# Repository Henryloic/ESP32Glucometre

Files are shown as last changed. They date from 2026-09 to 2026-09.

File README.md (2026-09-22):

# Guide utilisateur — Libre Sport Display ESP32-C3

**Libre Sport Display** is a small DIY device built with an ESP32-C3 and a 1.3-inch OLED screen. It displays the latest LibreLinkUp value and trend without opening the phone application.

## 1. Présentation

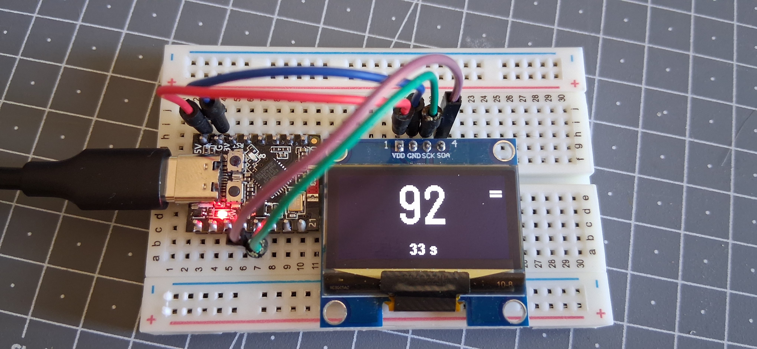
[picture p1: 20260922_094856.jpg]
Premier prototype


**Libre Sport Display** est un petit afficheur déporté basé sur un **ESP32-C3** et un écran OLED I²C de 1,3 pouce.

Il récupère périodiquement la dernière mesure disponible depuis le service LibreLinkUp et affiche uniquement les informations utiles pendant une activité sportive :

- la mesure instantanée en grand ;
- la tendance ;
- l’âge de la mesure ;
- l’état de la connexion en cas de problème.

L’objectif est de pouvoir consulter rapidement la valeur pendant une séance de tapis de course ou de vélo sur Zwift, sans avoir à ouvrir l’application sur le téléphone.

> [!IMPORTANT]
> Ce projet est un afficheur secondaire de confort. Il ne remplace ni l’application officielle, ni ses alarmes, ni les recommandations d’un professionnel de santé.

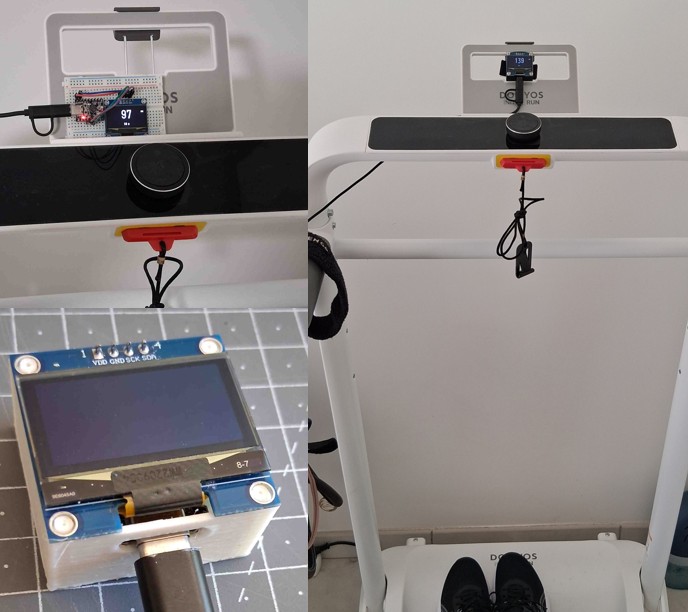
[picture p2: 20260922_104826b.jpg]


Boitier compact STL

---

## 2. Affichage

L’interface est volontairement très simple :

```text
┌─────────────────────┐
│              +      │
│        112          │
│        35 s         │
└─────────────────────┘
```

### Signification des tendances

| Code reçu | Affichage | Signification |
|---:|:---:|---|
| 1 | `--` | baisse rapide |
| 2 | `-` | baisse |
| 3 | `=` | stable |
| 4 | `+` | hausse |
| 5 | `++` | hausse rapide |

### Fraîcheur de la mesure

L’âge affiché sous la mesure permet de distinguer une donnée récente d’une donnée ancienne.

Exemples :

```text
35 s
```

```text
AGE 2 min
```

```text
ANCIEN 5 min
```

Lorsque le Wi-Fi est perdu, la dernière valeur valide reste visible :

```text
OFFLINE 4 min
```

Le programme privilégie le timestamp réel de la mesure lorsqu’il est disponible. Sinon, il affiche le temps écoulé depuis la réception de la donnée par l’ESP32.

---

## 3. Matériel nécessaire

- une carte ESP32-C3 ;
- un écran OLED I²C 1,3 pouce, 128 × 64 pixels ;
- contrôleur SH1106 dans la configuration actuelle ;
- quatre câbles Dupont ;
- une alimentation USB adaptée à l’ESP32-C3 ;
- un réseau Wi-Fi 2,4 GHz avec accès à Internet.

### Variante SSD1306

Si l’écran utilise un contrôleur SSD1306, remplacer dans le programme :

```cpp
U8G2_SH1106_128X64_NONAME_F_HW_I2C
```

par :

```cpp
U8G2_SSD1306_128X64_NONAME_F_HW_I2C
```

---

## 4. Câblage

Configuration utilisée dans le programme :

| Écran OLED | ESP32-C3 |
|---|---:|
| VCC | 3,3 V |
| GND | GND |
| SDA | GPIO 8 |
| SCL | GPIO 9 |

L’adresse I²C configurée est `0x3C`.

> [!CAUTION]
> L’ordre physique des broches peut varier selon le modèle d’écran. Vérifier les marquages `VCC`, `GND`, `SDA` et `SCL` imprimés sur le module avant de l’alimenter.

---

## 5. Logiciels nécessaires

### Arduino IDE

Installer une version récente de l’IDE Arduino, puis ajouter la prise en charge des cartes ESP32.

### Bibliothèques Arduino

Installer depuis le gestionnaire de bibliothèques :

- **U8g2** pour l’écran OLED ;
- **ArduinoJson** pour l’analyse des réponses JSON.

Les bibliothèques suivantes sont fournies avec l’environnement ESP32 :

- `WiFi` ;
- `WiFiClientSecure` ;
- `HTTPClient` ;
- `Wire` ;
- `time` ;
- `mbedtls`.

---

## 6. Réglages conseillés dans l’IDE Arduino

Les intitulés exacts peuvent varier selon la carte sélectionnée.

Réglages principaux :

```text
Carte : modèle ESP32-C3 correspondant à la carte utilisée
USB CDC On Boot : Enabled
Vitesse du moniteur série : 115200 bauds
Port : port série associé à l’ESP32-C3
```

Conserver les mêmes paramètres USB que ceux utilisés avec succès pour le test individuel du moniteur série.

---

## 7. Configuration personnelle

Dans la partie supérieure du programme, renseigner uniquement le bloc prévu à cet effet :

```cpp
// Réseau Wi-Fi de la maison
const char* WIFI_SSID = "NOM_DU_WIFI";
const char* WIFI_PASSWORD = "MOT_DE_PASSE_WIFI";

// Compte LibreLinkUp
const char* LIBRE_EMAIL = "ADRESSE_EMAIL_LIBRELINKUP";
const char* LIBRE_PASSWORD = "MOT_DE_PASSE_LIBRELINKUP";
```

### Recommandation pour un dépôt public

Ne jamais publier les identifiants réels dans GitHub.

Pour une version propre du dépôt, placer les secrets dans un fichier séparé nommé `secret.h` :

```cpp
#pragma once

const char* WIFI_SSID = "NOM_DU_WIFI";
const char* WIFI_PASSWORD = "MOT_DE_PASSE_WIFI";

const char* LIBRE_EMAIL = "ADRESSE_EMAIL_LIBRELINKUP";
const char* LIBRE_PASSWORD = "MOT_DE_PASSE_LIBRELINKUP";
```

Puis inclure ce fichier dans le programme principal :

```cpp
#include "secret.h"
```

Ajouter impérativement `secret.h` dans le fichier `.gitignore` :

```gitignore
secret.h
```

Il est également utile de fournir un modèle sans identifiants :

```text
secret.example.h
```

---

## 8. Organisation recommandée du dépôt

```text
Libre-Sport-Display/
├── LibreSportDisplay.ino
├── secret.example.h
├── .gitignore
├── README.md
├── USER_GUIDE.md
└── LICENSE
```

Le fichier réel `secret.h` reste uniquement sur l’ordinateur utilisé pour compiler le projet.

---

## 9. Premier démarrage

### Étape 1 — Vérifier le câblage

Contrôler les quatre connexions de l’écran :

```text
VCC → 3,3 V
GND → GND
SDA → GPIO 8
SCL → GPIO 9
```

### Étape 2 — Compiler et téléverser

1. connecter l’ESP32-C3 en USB ;
2. sélectionner la bonne carte ;
3. sélectionner le bon port ;
4. compiler le programme ;
5. téléverser le programme.

### Étape 3 — Ouvrir le moniteur série

Régler le moniteur série sur :

```text
115200 bauds
```

Puis appuyer une fois sur le bouton `RESET` de la carte si nécessaire.

Le début attendu ressemble à ceci :

```text
========================================
 ESP32-C3 LIBRE SPORT
 PORT SERIE OPERATIONNEL
========================================
Initialisation I2C...
Initialisation OLED...
OLED initialise
```

### Étape 4 — Vérifier le Wi-Fi

Lorsque la connexion fonctionne :

```text
Wi-Fi connecte
Adresse IP : 192.168.x.x
Puissance Wi-Fi : -xx dBm
```

### Étape 5 — Vérifier l’heure

Après synchronisation NTP :

```text
Heure NTP synchronisee
Heure ESP32 : 15:42:18
```

### Étape 6 — Vérifier LibreLinkUp

Le programme affiche ensuite les étapes suivantes :

```text
REQUETE LOGIN
RECUPERATION DU PATIENT
RECUPERATION DE LA MESURE
```

Lorsque tout fonctionne :

```text
Token recu correctement
Patient trouve : ...
MESURE RECUE AVEC SUCCES
Valeur : 112
Tendance affichee : +
Timestamp interprete : OUI
```

---

## 10. Fonctionnement réseau

Le programme suit cette séquence :

```text
Connexion Wi-Fi
      ↓
Synchronisation NTP
      ↓
Authentification LibreLinkUp
      ↓
Détection éventuelle du serveur régional
      ↓
Récupération du patient
      ↓
Récupération de la dernière mesure
      ↓
Actualisation toutes les 60 secondes
```

La valeur suivante définit la période d’interrogation :

```cpp
constexpr unsigned long API_INTERVAL_MS = 60000UL;
```

`60000` millisecondes correspondent à une minute.

---

## 11. Redirection régionale

La première authentification peut ne pas fournir directement le token. Le serveur peut d’abord demander une redirection vers une région spécifique.

Exemple de diagnostic :

```text
Redirection regionale demandee
Region demandee par LibreLinkUp : eu
Nouveau serveur : https://api-eu.libreview.io
```

Le programme recommence alors automatiquement l’authentification sur le serveur régional.

Régions prévues dans le code :

- `eu` ;
- `eu2` ;
- `fr` ;
- `de` ;
- `us` ;
- `ca` ;
- `ap` ;
- `au` ;
- `jp`.

---

## 12. Messages affichés sur l’OLED

| Message | Signification |
|---|---|
| `DEMARRAGE` | initialisation du programme |
| `CONNEXION WIFI` | tentative de connexion au réseau |
| `WIFI ABSENT` | réseau indisponible ou identifiants incorrects |
| `SYNCHRO HEURE` | synchronisation NTP en cours |
| `CONNEXION LIBRE` | authentification LibreLinkUp en cours |
| `TOKEN ABSENT` | aucune information d’authentification exploitable reçue |
| `PATIENT ABSENT` | aucun identifiant patient détecté |
| `LECTURE` | récupération de la mesure en cours |
| `LIVE` | dernière mesure récupérée avec succès |
| `SESSION EXPIREE` | nouvelle authentification nécessaire |
| `ERREUR SERVEUR` | réponse HTTP non valide |
| `JSON INVALIDE` | réponse reçue mais impossible à analyser |
| `MESURE ABSENTE` | bloc de mesure introuvable dans la réponse |

---

## 13. Dépannage

### Aucun message dans le moniteur série

Vérifier :

1. que le débit est réglé sur `115200` ;
2. que le bon port est sélectionné ;
3. que `USB CDC On Boot` est activé pour l’ESP32-C3 ;
4. que le même profil de carte que pour le test série fonctionnel est utilisé ;
5. qu’un redémarrage est effectué après l’ouverture du moniteur série.

Le programme attend brièvement l’initialisation USB au démarrage, mais il ne bloque pas indéfiniment si aucun moniteur série n’est ouvert.

### L’écran reste noir

Vérifier :

- l’alimentation 3,3 V ;
- la masse commune ;
- SDA sur GPIO 8 ;
- SCL sur GPIO 9 ;
- l’adresse `0x3C` ;
- le contrôleur SH1106 ou SSD1306 ;
- le résultat d’un scanner I²C.

Si l’écran est détecté à l’adresse `0x3D`, modifier :

```cpp
constexpr uint8_t OLED_ADDRESS = 0x3D;
```

### Message `WIFI ABSENT`

Vérifier :

- le nom exact du réseau ;
- le mot de passe Wi-Fi ;
- la présence d’un réseau 2,4 GHz ;
- la qualité du signal ;
- l’absence de portail captif.

### Message `TOKEN ABSENT`

Consulter la section complète :

```text
========== REPONSE LOGIN ==========
```

Les causes possibles sont notamment :

- une réponse de redirection régionale non reconnue ;
- une modification du format JSON ;
- une version d’API devenue incompatible ;
- une étape d’acceptation ou de validation attendue par le compte ;
- un compte LibreLinkUp ou un mot de passe incorrect ;
- une réponse d’erreur contenue dans un HTTP 200.

Ne jamais publier la réponse complète si elle contient un token, un identifiant de compte ou une donnée personnelle.

### Code HTTP 401

Cela indique généralement que la session n’est plus acceptée.

Le programme efface alors le token et l’identifiant patient afin de recommencer l’authentification lors de la prochaine tentative.

### Code HTTP négatif

Un code négatif provient généralement de la couche réseau de l’ESP32, par exemple :

- échec DNS ;
- délai dépassé ;
- connexion TLS impossible ;
- perte du Wi-Fi.

### `Timestamp interprete : NON`

La mesure peut tout de même être affichée. Dans ce cas, l’âge est calculé depuis la réception par l’ESP32 plutôt que depuis l’heure réelle de la mesure.

Pour prendre en charge un nouveau format, ajouter une variante dans la fonction :

```cpp
parseFactoryTimestamp()
```

### Valeur présente mais ancienne

L’âge affiché continue d’augmenter même si le serveur ne répond plus.

La dernière valeur n’est donc pas présentée comme une nouvelle mesure. L’écran affiche progressivement :

```text
35 s
AGE 2 min
ANCIEN 5 min
```

---

## 14. Diagnostic sans exposer les données sensibles

Pour demander de l’aide, copier uniquement :

- le code HTTP ;
- le champ `status` ;
- le message d’erreur ;
- la région demandée ;
- la structure générale du JSON après suppression des données sensibles.

Masquer systématiquement :

- l’adresse e-mail ;
- le mot de passe ;
- le token ;
- l’Account-Id ;
- l’identifiant du patient ;
- les données personnelles présentes dans la réponse.

Exemple de réponse nettoyée :

```json
{
  "status": 0,
  "data": {
    "redirect": true,
    "region": "eu"
  }
}
```

---

## 15. Sécurité HTTPS

La version de prototypage utilise :

```cpp
secureClient.setInsecure();
```

La communication reste chiffrée, mais le certificat présenté par le serveur n’est pas vérifié par l’ESP32.

Pour une version plus aboutie, remplacer cette configuration par la validation d’un certificat racine :

```cpp
secureClient.setCACert(rootCertificate);
```

Cette évolution nécessite de maintenir le certificat utilisé par le projet.

---

## 16. Bonnes pratiques GitHub

Avant chaque publication :

- vérifier que `secret.h` n’est pas suivi par Git ;
- rechercher toute adresse e-mail personnelle dans le dépôt ;
- rechercher tout mot de passe ;
- rechercher les chaînes commençant par un token ;
- supprimer les captures du moniteur série contenant des données sensibles ;
- fournir seulement `secret.example.h`.

Exemple de `.gitignore` :

```gitignore
# Identifiants locaux
secret.h

# Fichiers temporaires Arduino
*.bin
*.elf
*.map

# Fichiers système
.DS_Store
Thumbs.db

# IDE
.vscode/
```

---

## 17. Limites connues

- Le projet dépend d’un service distant et d’un accès Internet.
- Le format des réponses ou les points d’accès peuvent évoluer.
- Le projet utilise une API communautaire non garantie pour un appareil embarqué.
- L’actualisation distante peut être différente du rythme de production des mesures par le capteur.
- L’âge réel dépend de la présence et du format du timestamp dans la réponse.
- L’écran monochrome ne permet pas d’utiliser un code couleur.
- Le prototype ne vérifie pas encore le certificat TLS du serveur.

---

## 18. Utilisation pendant le sport

Avant une séance :

1. allumer l’ESP32-C3 ;
2. attendre l’affichage d’une valeur ;
3. vérifier que l’âge est faible ;
4. vérifier que la tendance est renseignée ;
5. conserver le téléphone et les alarmes officielles disponibles.

Pendant la séance, l’information la plus importante est l’âge de la donnée :

```text
112   +   35 s
```

Une mesure affichée avec `ANCIEN` ou `OFFLINE` ne doit pas être interprétée comme une donnée actuelle.

---

## 19. Résumé rapide

```text
Valeur  : mesure la plus récente reçue
Tendance: --, -, =, + ou ++
Age     : ancienneté de la mesure
LIVE    : récupération réussie
OFFLINE : dernière mesure conservée, réseau indisponible
```

Le projet est conçu pour rester simple, immédiatement lisible et utilisable sans interaction pendant une activité sportive.

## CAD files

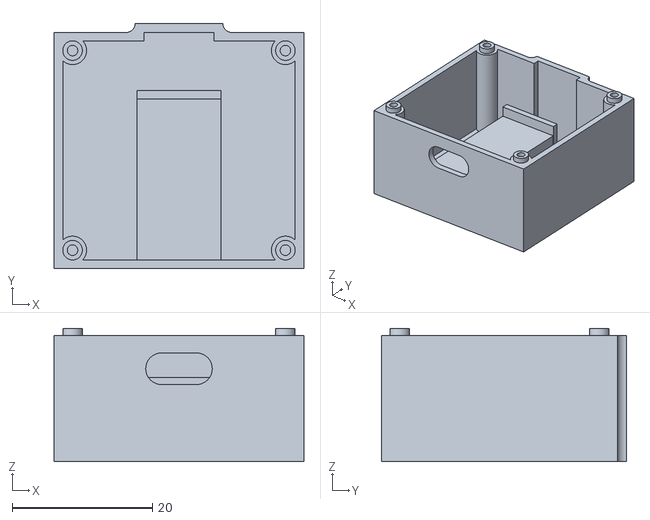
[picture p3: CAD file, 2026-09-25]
boitier.stl
35.7 x 34.9 x 19.0

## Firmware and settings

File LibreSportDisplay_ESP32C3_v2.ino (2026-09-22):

#include <WiFi.h>
#include <WiFiClientSecure.h>
#include <HTTPClient.h>
#include <ArduinoJson.h>
#include <U8g2lib.h>
#include <Wire.h>
#include "mbedtls/sha256.h"

/*
  LibreSportDisplay_ESP32C3_v2.ino

  Deux corrections :
  1) Le demarrage n'attend plus l'ouverture du moniteur serie.
  2) L'age affiche est uniquement le nombre de secondes ecoulees
     depuis la derniere requete API REUSSIE.

  Affichage : valeur, tendance, age de la derniere reponse valide.
*/

// =====================================================
// 1. RESEAU WI-FI DE LA MAISON
// =====================================================
const char* WIFI_SSID     = "NOM_DU_WIFI_MAISON";
const char* WIFI_PASSWORD = "MOT_DE_PASSE_WIFI";

// =====================================================
// 2. COMPTE LIBRELINKUP
// =====================================================
const char* LIBRE_EMAIL    = "ADRESSE_DU_COMPTE_LIBRELINKUP";
const char* LIBRE_PASSWORD = "MOT_DE_PASSE_LIBRELINKUP";

String apiBaseUrl = "https://api-eu.libreview.io";
const char* API_PRODUCT = "llu.android";
const char* API_VERSION = "4.17.0";

// =====================================================
// 3. ECRAN OLED SH1106 128 x 64
// =====================================================
U8G2_SH1106_128X64_NONAME_F_HW_I2C display(U8G2_R0, U8X8_PIN_NONE);
constexpr int I2C_SDA = 8;
constexpr int I2C_SCL = 9;

// =====================================================
// 4. TEMPORISATIONS
// =====================================================
constexpr unsigned long API_INTERVAL_MS          = 60000UL;
constexpr unsigned long API_RETRY_AFTER_ERROR_MS = 15000UL;
constexpr unsigned long WIFI_RETRY_MS            = 10000UL;
constexpr unsigned long SCREEN_UPDATE_MS         = 500UL;
constexpr uint16_t HTTP_TIMEOUT_MS                = 15000;

// Fraicheur d'affichage uniquement, pas des seuils medicaux.
constexpr unsigned long AGE_RECENT_SECONDS = 90;
constexpr unsigned long AGE_OLD_SECONDS    = 180;

// =====================================================
// 5. DONNEES
// =====================================================
struct GlucoseData {
  int value = -1;
  int trend = 0;
  bool valid = false;

  // Instant local de la derniere requete API reussie.
  unsigned long lastSuccessfulRequestMillis = 0;
};

GlucoseData glucose;
String authToken = "";
String patientId = "";
String accountIdHash = "";
String statusMessage = "DEMARRAGE";

unsigned long lastApiAttempt = 0;
unsigned long lastWifiAttempt = 0;
unsigned long lastScreenUpdate = 0;
unsigned long currentApiInterval = 0;
bool requestInProgress = false;

// =====================================================
// 6. OUTILS
// =====================================================
String sha256(const String& input) {
  unsigned char hash[32];
  mbedtls_sha256_context context;
  mbedtls_sha256_init(&context);
  mbedtls_sha256_starts(&context, 0);
  mbedtls_sha256_update(
    &context,
    reinterpret_cast<const unsigned char*>(input.c_str()),
    input.length()
  );
  mbedtls_sha256_finish(&context, hash);
  mbedtls_sha256_free(&context);

  char result[65];
  for (int i = 0; i < 32; i++) sprintf(result + i * 2, "%02x", hash[i]);
  result[64] = '\0';
  return String(result);
}

String trendText(int trend) {
  switch (trend) {
    case 1: return "--";
    case 2: return "-";
    case 3: return "=";
    case 4: return "+";
    case 5: return "++";
    default: return "?";
  }
}

// CORRECTION 2 : age calcule uniquement depuis la derniere requete reussie.
unsigned long getRequestAgeSeconds() {
  if (!glucose.valid) return 0;
  return (millis() - glucose.lastSuccessfulRequestMillis) / 1000UL;
}

String formatAge(unsigned long seconds) {
  // Affichage en secondes jusqu'a 59 min 59 s pour voir l'incrementation.
  if (seconds < 3600UL) return String(seconds) + " s";
  return String(seconds / 60UL) + " min";
}

String normalizeRegion(String region) {
  region.toLowerCase();
  region.trim();
  return region;
}

String baseUrlForRegion(String region) {
  region = normalizeRegion(region);
  if (region == "eu")  return "https://api-eu.libreview.io";
  if (region == "eu2") return "https://api-eu2.libreview.io";
  if (region == "fr")  return "https://api-fr.libreview.io";
  if (region == "de")  return "https://api-de.libreview.io";
  if (region == "us")  return "https://api.libreview.io";
  if (region == "ca")  return "https://api-ca.libreview.io";
  if (region == "au")  return "https://api-au.libreview.io";
  if (region == "ap")  return "https://api-ap.libreview.io";
  if (region == "ae")  return "https://api-ae.libreview.io";
  if (region == "jp")  return "https://api-jp.libreview.io";
  return "";
}

String jsonString(JsonVariantConst object, const char* k1,
                  const char* k2 = nullptr, const char* k3 = nullptr) {
  if (k1 && !object[k1].isNull()) return object[k1].as<String>();
  if (k2 && !object[k2].isNull()) return object[k2].as<String>();
  if (k3 && !object[k3].isNull()) return object[k3].as<String>();
  return "";
}

int jsonInt(JsonVariantConst object, const char* k1,
            const char* k2 = nullptr, int fallback = -1) {
  if (k1 && !object[k1].isNull()) return object[k1].as<int>();
  if (k2 && !object[k2].isNull()) return object[k2].as<int>();
  return fallback;
}

// =====================================================
// 7. AFFICHAGE
// =====================================================
void drawCenteredText(const String& text, int y, const uint8_t* font) {
  display.setFont(font);
  int x = (128 - display.getUTF8Width(text.c_str())) / 2;
  if (x < 0) x = 0;
  display.drawUTF8(x, y, text.c_str());
}

void drawStartupScreen(const String& line1, const String& line2) {
  display.clearBuffer();
  drawCenteredText(line1, 27, u8g2_font_helvB12_tf);
  drawCenteredText(line2, 49, u8g2_font_helvR08_tf);
  display.sendBuffer();
}

void drawScreen() {
  display.clearBuffer();

  if (!glucose.valid) {
    drawCenteredText("---", 37, u8g2_font_logisoso28_tn);
    drawCenteredText(statusMessage, 60, u8g2_font_helvR08_tf);
    display.sendBuffer();
    return;
  }

  unsigned long age = getRequestAgeSeconds();
  drawCenteredText(String(glucose.value), 38, u8g2_font_logisoso30_tn);

  String trend = trendText(glucose.trend);
  display.setFont(u8g2_font_helvB14_tf);
  int trendWidth = display.getUTF8Width(trend.c_str());
  display.drawUTF8(126 - trendWidth, 20, trend.c_str());

  String ageText;
  if (WiFi.status() != WL_CONNECTED) {
    ageText = "HORS LIGNE " + formatAge(age);
  } else if (age <= AGE_RECENT_SECONDS) {
    ageText = formatAge(age);
  } else if (age <= AGE_OLD_SECONDS) {
    ageText = "AGE " + formatAge(age);
  } else {
    ageText = "ANCIEN " + formatAge(age);
  }

  drawCenteredText(ageText, 61, u8g2_font_helvB08_tf);

  if (age > AGE_OLD_SECONDS) {
    display.drawFrame(0, 0, 128, 64);
    display.drawFrame(2, 2, 124, 60);
  }

  display.sendBuffer();
}

// =====================================================
// 8. WI-FI
// =====================================================
void connectWiFi() {
  if (WiFi.status() == WL_CONNECTED) return;

  statusMessage = "CONNEXION WIFI";
  drawStartupScreen("Wi-Fi", WIFI_SSID);
  Serial.print("Connexion Wi-Fi : ");
  Serial.println(WIFI_SSID);

  WiFi.mode(WIFI_STA);
  WiFi.setAutoReconnect(true);
  WiFi.persistent(false);
  WiFi.begin(WIFI_SSID, WIFI_PASSWORD);

  unsigned long start = millis();
  while (WiFi.status() != WL_CONNECTED && millis() - start < 15000UL) {
    delay(250);
    Serial.print(".");
  }
  Serial.println();

  if (WiFi.status() == WL_CONNECTED) {
    statusMessage = "WIFI OK";
    Serial.print("Wi-Fi OK, IP : ");
    Serial.println(WiFi.localIP());
    drawStartupScreen("Wi-Fi OK", WiFi.localIP().toString());
  } else {
    statusMessage = "WIFI ABSENT";
    Serial.println("Wi-Fi absent");
    drawStartupScreen("Wi-Fi absent", "Nouvel essai");
  }
}

// =====================================================
// 9. EN-TETES HTTPS
// =====================================================
void configureCommonHeaders(HTTPClient& http) {
  http.addHeader("Content-Type", "application/json");
  http.addHeader("Accept", "application/json");
  http.addHeader("product", API_PRODUCT);
  http.addHeader("version", API_VERSION);
  http.addHeader("Cache-Control", "no-cache");
}

void configureAuthenticatedHeaders(HTTPClient& http) {
  configureCommonHeaders(http);
  http.addHeader("Authorization", "Bearer " + authToken);
  if (accountIdHash.length() > 0) http.addHeader("Account-Id", accountIdHash);
}

// =====================================================
// 10. AUTHENTIFICATION
// =====================================================
bool authenticateLibreLinkUp() {
  if (WiFi.status() != WL_CONNECTED) return false;

  // Deux passages pour prendre en charge une redirection regionale.
  for (int attempt = 0; attempt < 2; attempt++) {
    statusMessage = "CONNEXION LIBRE";
    drawScreen();

    WiFiClientSecure client;
    client.setInsecure();
    client.setTimeout(HTTP_TIMEOUT_MS / 1000);

    HTTPClient http;
    http.setTimeout(HTTP_TIMEOUT_MS);
    String url = apiBaseUrl + "/llu/auth/login";

    Serial.print("Login : ");
    Serial.println(url);

    if (!http.begin(client, url)) {
      statusMessage = "HTTPS IMPOSSIBLE";
      return false;
    }

    configureCommonHeaders(http);

    JsonDocument request;
    request["email"] = LIBRE_EMAIL;
    request["password"] = LIBRE_PASSWORD;
    String body;
    serializeJson(request, body);

    int code = http.POST(body);
    String response = http.getString();
    http.end();

    Serial.print("Login HTTP : ");
    Serial.println(code);

    if (code < 200 || code >= 300) {
      statusMessage = "LOGIN HTTP " + String(code);
      return false;
    }

    JsonDocument json;
    if (deserializeJson(json, response)) {
      statusMessage = "JSON LOGIN";
      return false;
    }

    bool redirect = json["data"]["redirect"] | false;
    String region = json["data"]["region"] | "";

    if (redirect || region.length() > 0) {
      String newUrl = baseUrlForRegion(region);
      Serial.print("Redirection region : ");
      Serial.println(region);
      if (newUrl.length() == 0 || newUrl == apiBaseUrl) {
        statusMessage = "REGION " + region;
        return false;
      }
      apiBaseUrl = newUrl;
      continue;
    }

    authToken = json["data"]["authTicket"]["token"] | "";
    if (authToken.length() == 0) authToken = json["data"]["token"] | "";
    if (authToken.length() == 0) authToken = json["authTicket"]["token"] | "";

    String accountId = json["data"]["user"]["id"] | "";

    if (authToken.length() == 0) {
      statusMessage = "TOKEN ABSENT";
      Serial.println("Token absent");
      return false;
    }

    accountIdHash = accountId.length() ? sha256(accountId) : "";
    statusMessage = "LOGIN OK";
    Serial.println("Authentification OK");
    return true;
  }

  return false;
}

// =====================================================
// 11. PATIENT
// =====================================================
bool fetchPatientId() {
  WiFiClientSecure client;
  client.setInsecure();
  client.setTimeout(HTTP_TIMEOUT_MS / 1000);

  HTTPClient http;
  http.setTimeout(HTTP_TIMEOUT_MS);
  String url = apiBaseUrl + "/llu/connections";

  if (!http.begin(client, url)) return false;
  configureAuthenticatedHeaders(http);

  int code = http.GET();
  String response = http.getString();
  http.end();

  Serial.print("Connections HTTP : ");
  Serial.println(code);

  if (code == 401) {
    authToken = "";
    patientId = "";
    return false;
  }
  if (code < 200 || code >= 300) return false;

  JsonDocument json;
  if (deserializeJson(json, response)) return false;

  JsonVariantConst first = json["data"][0];
  patientId = jsonString(first, "patientId", "id");

  if (patientId.length() == 0) {
    statusMessage = "PATIENT ABSENT";
    return false;
  }

  Serial.println("Patient OK");
  return true;
}

// =====================================================
// 12. MESURE
// =====================================================
bool fetchLatestMeasurement() {
  if (WiFi.status() != WL_CONNECTED) {
    statusMessage = "WIFI ABSENT";
    return false;
  }

  if (authToken.length() == 0 && !authenticateLibreLinkUp()) return false;
  if (patientId.length() == 0 && !fetchPatientId()) return false;

  statusMessage = "LECTURE";

  WiFiClientSecure client;
  client.setInsecure();
  client.setTimeout(HTTP_TIMEOUT_MS / 1000);

  HTTPClient http;
  http.setTimeout(HTTP_TIMEOUT_MS);
  String url = apiBaseUrl + "/llu/connections/" + patientId + "/graph";

  if (!http.begin(client, url)) return false;
  configureAuthenticatedHeaders(http);

  int code = http.GET();
  String response = http.getString();
  http.end();

  Serial.print("Mesure HTTP : ");
  Serial.println(code);

  if (code == 401) {
    authToken = "";
    patientId = "";
    statusMessage = "SESSION EXPIREE";
    return false;
  }
  if (code < 200 || code >= 300) {
    statusMessage = "ERREUR SERVEUR";
    return false;
  }

  JsonDocument json;
  if (deserializeJson(json, response)) {
    statusMessage = "JSON INVALIDE";
    return false;
  }

  JsonVariantConst measurement = json["data"]["connection"]["glucoseMeasurement"];
  if (measurement.isNull()) {
    measurement = json["data"]["connection"]["glucoseItem"];
  }
  if (measurement.isNull()) {
    statusMessage = "MESURE ABSENTE";
    return false;
  }

  int newValue = jsonInt(measurement, "Value", "value", -1);
  int newTrend = jsonInt(measurement, "TrendArrow", "trend", 0);

  if (newValue < 0) {
    statusMessage = "VALEUR ABSENTE";
    return false;
  }

  // Mise a jour uniquement apres une reponse valide.
  glucose.value = newValue;
  glucose.trend = newTrend;
  glucose.valid = true;
  glucose.lastSuccessfulRequestMillis = millis(); // Age remis a zero ici.
  statusMessage = "LIVE";

  Serial.print("Valeur : ");
  Serial.println(glucose.value);
  Serial.print("Tendance : ");
  Serial.println(trendText(glucose.trend));
  Serial.println("Age de requete remis a 0 s");

  return true;
}

// =====================================================
// 13. GESTION PERIODIQUE
// =====================================================
void manageWiFi() {
  if (WiFi.status() == WL_CONNECTED) return;

  if (lastWifiAttempt == 0 || millis() - lastWifiAttempt >= WIFI_RETRY_MS) {
    lastWifiAttempt = millis();
    connectWiFi();
    if (WiFi.status() == WL_CONNECTED) {
      lastApiAttempt = 0;
      currentApiInterval = 0;
    }
  }
}

void manageApi() {
  if (WiFi.status() != WL_CONNECTED || requestInProgress) return;

  bool firstRequest = (lastApiAttempt == 0);
  bool elapsed = (currentApiInterval == 0) ||
                 (millis() - lastApiAttempt >= currentApiInterval);
  if (!firstRequest && !elapsed) return;

  requestInProgress = true;
  lastApiAttempt = millis();

  Serial.println("Interrogation LibreLinkUp");
  bool success = fetchLatestMeasurement();

  if (success) {
    currentApiInterval = API_INTERVAL_MS;
    Serial.println("Prochaine requete dans 60 s");
  } else {
    currentApiInterval = API_RETRY_AFTER_ERROR_MS;
    Serial.println("Echec, nouvel essai dans 15 s");
  }

  requestInProgress = false;
}

// =====================================================
// 14. SETUP
// =====================================================
void setup() {
  Serial.begin(115200);

  // CORRECTION 1 : aucune attente de l'ouverture du port serie.
  // L'ESP32 demarre donc aussi avec un simple chargeur USB.
  delay(500);

  Serial.println();
  Serial.println("ESP32-C3 GLUCOSE MONITOR");
  Serial.println("Demarrage autonome");

  Wire.begin(I2C_SDA, I2C_SCL);
  delay(500);
  display.begin();
  display.setContrast(255);
  drawStartupScreen("Libre Sport", "Demarrage");

  connectWiFi();

  lastApiAttempt = 0;
  currentApiInterval = 0;
}

// =====================================================
// 15. LOOP
// =====================================================
void loop() {
  manageWiFi();
  manageApi();

  if (millis() - lastScreenUpdate >= SCREEN_UPDATE_MS) {
    lastScreenUpdate = millis();
    drawScreen();
  }

  delay(20);
}
